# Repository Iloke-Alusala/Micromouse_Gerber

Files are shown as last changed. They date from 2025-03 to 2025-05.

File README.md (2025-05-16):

# 🐭 Micromouse Power Subsystem – UCT EEE3088F Design Project

This repository contains the KiCad schematic and PCB design files for the **power subsystem** of a modular micromouse robot, developed as part of the EEE3088F final year design course at the University of Cape Town.

---
# ⚠️ Warning: Do Not Use As-Is
This repository contains schematic and PCB design files for a micromouse power subsystem. These designs are provided for reference and educational purposes only.

Several components in the schematic and PCB do not function as intended due to design or implementation limitations, though many of the core design choices and ideas remain valid. Always check all datasheets of ICs and components used in a given section before adopting this to your own design.**

Therefore, this hardware should not be used as-is for production or critical applications.You are encouraged to use the files for inspiration or as a starting point, but please verify and test all circuits thoroughly before use in any real-world system.
---

## 📌 Project Overview

Micromouse robots are autonomous robots that solve mazes using onboard logic and control systems. This project focused on developing the **power subsystem**, a critical part of the micromouse architecture. The design was constrained by size (82mm x 60mm), budget (R600), and modularity requirements. The subsystem is responsible for:

- Supplying **regulated voltages** from the LiPo battery (3.3V and 5V)
- Enabling **bidirectional motor control**
- Charging a **single-cell LiPo battery** (200mA/600mA modes) from Type-C charging
- Providing **external load switching** for sensors and logic
- Supporting **testability** and **fault isolation**

---

## 🔧 Key Design Goals

- **Bidirectional Motor Driving** via dual DRV8833 H-Bridge ICs
- **Type C Battery Charging Support** using TP4056-MS and XL1509 buck converter, as well as the CH224K PD negotiator
- **High-Side Load Switching** through AP22966 ICs (1A per channel)
- **Modular Power Path** allowing buck and charger stages to be tested independently
- **Design-for-Testability** with test points, jumper-control pads, and 1206 resistor footprints
- **Battery Monitoring** using INA219 and I2C connection to external microcontroller
- **Regulated 5V and 3.3V ouptu voltages supporting 300mA and 1.5A outputs**
- **Physical ON-OFF switch for disabling and enabling battery connection to the board**

---

## 📁 Repository Structure
```bash
Micromouse_Power_Subsystem/
├── KiCad_Project/
├── power_subsystem.kicad_sch        # Schematic file
│  ├── power_subsystem.kicad_pcb        # PCB layout
│   ├── project.kicad_pro                # KiCad project file
│   └── gerber/                          # Output Gerber files
├── README.md
##

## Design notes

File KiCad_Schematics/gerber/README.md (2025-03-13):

# Micromouse_Gerber
A repository to store gerber files for our 3rd Year Micromouse Project. Make a mouse move through a maze

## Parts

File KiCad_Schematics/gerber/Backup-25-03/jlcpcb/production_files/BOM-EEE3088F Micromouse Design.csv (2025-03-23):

Comment | Designator | Footprint | LCSC | Quantity
0.1mF | C9 | C_0402_1005Metric_Pad0.74x0.62mm_HandSolder |  | 1
0.1mF | C7 | C_0402_1005Metric_Pad0.74x0.62mm_HandSolder |  | 1
0.1mF | C5 | C_0402_1005Metric_Pad0.74x0.62mm_HandSolder |  | 1
0.15 | R1 | R_1206_3216Metric_Pad1.30x1.75mm_HandSolder |  | 1
0.1mF | C12 | C_0402_1005Metric_Pad0.74x0.62mm_HandSolder |  | 1
DRV8837 | U2 | WSON-8-1EP_2x2mm_P0.5mm_EP0.9x1.6mm |  | 1
0.1mF | C4 | C_0402_1005Metric_Pad0.74x0.62mm_HandSolder |  | 1
0.1mF | C6 | C_0402_1005Metric_Pad0.74x0.62mm_HandSolder |  | 1
0.1mF | C3 | C_0402_1005Metric_Pad0.74x0.62mm_HandSolder |  | 1
DRV8837 | U3 | WSON-8-1EP_2x2mm_P0.5mm_EP0.9x1.6mm |  | 1
Conn_02x16_Odd_Even | J1 | PinSocket_2x16_P2.54mm_Vertical |  | 1
DRV8837 | U5 | WSON-8-1EP_2x2mm_P0.5mm_EP0.9x1.6mm |  | 1
0.1mF | C8 | C_0402_1005Metric_Pad0.74x0.62mm_HandSolder |  | 1
0.1mF | C2 | C_0402_1005Metric_Pad0.74x0.62mm_HandSolder |  | 1
INA219AxD | U1 | SOIC-8_3.9x4.9mm_P1.27mm |  | 1
0.1mF | C10 | C_0402_1005Metric_Pad0.74x0.62mm_HandSolder |  | 1
Conn_01x02 | J2 | JST_EH_B2B-EH-A_1x02_P2.50mm_Vertical |  | 1
0.1mF | C13 | C_0402_1005Metric_Pad0.74x0.62mm_HandSolder |  | 1
0.1mF | C11 | C_0402_1005Metric_Pad0.74x0.62mm_HandSolder |  | 1
DRV8837 | U4 | WSON-8-1EP_2x2mm_P0.5mm_EP0.9x1.6mm |  | 1

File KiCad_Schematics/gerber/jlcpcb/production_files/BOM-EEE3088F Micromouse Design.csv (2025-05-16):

Comment | Designator | Footprint | LCSC | Quantity
100uF | C56 | C_1206_3216Metric_Pad1.33x1.80mm_HandSolder | C15008 | 1
10uF | C41,C44,C45 | C_0805_2012Metric_Pad1.18x1.45mm_HandSolder | C15850 | 3
1nF | C35,C36 | C_0603_1608Metric | C1588 | 2
10k | R19 | R_0603_1608Metric_Pad0.98x0.95mm_HandSolder | C17414 | 1
330 | R28 | R_0805_2012Metric_Pad1.20x1.40mm_HandSolder | C17630 | 1
1 | R26,R35 | R_1206_3216Metric_Pad1.30x1.75mm_HandSolder | C17928 | 2
4.7k | R27 | R_1206_3216Metric_Pad1.30x1.75mm_HandSolder | C17936 | 1
AO3400A | Q2 | SOT-23 | C20917 | 1
22uH | L3,L4,L5 | L_7.3x7.3_H4.5 | C22463825 | 3
270 | R34 | R_0603_1608Metric_Pad0.98x0.95mm_HandSolder | C22966 | 1
2.2uF | C29,C31 | C_0603_1608Metric_Pad1.08x0.95mm_HandSolder | C23630 | 2
0.82 | R29,R30,R31,R32 | R_0603_1608Metric_Pad0.98x0.95mm_HandSolder | C3013351 | 4
SS32 | D3 | D_SMA | C34897 | 1
2.2k | R33 | R_0603_1608Metric_Pad0.98x0.95mm_HandSolder | C4190 | 1
AP22966DC8-7 | U13 | AP22966DC8-7 | C441830 | 1
DRV8833PW | U11,U12 | TSSOP-16_4.4x5mm_P0.65mm | C50506 | 2
1uF | C1,C27,C32,C33,C34 | C_0402_1005Metric_Pad0.74x0.62mm_HandSolder | C52923 | 5
10nF | C28,C30 | C_0603_1608Metric | C57112 | 2
XL1509-5.0 | U14 | SOIC-8_3.9x4.9mm_P1.27mm | C61063 | 1
100uF | C26,C48,C49,C50 | CP_EIA-3528-21_Kemet-B | C7196 | 4
TP4056-42-ESOP8 | U15 | SOIC-8-1EP_3.9x4.9mm_P1.27mm_EP2.41x3.3mm_ThermalVias | C7473158 | 1
47uF | C14,C15 | C_1206_3216Metric_Pad1.33x1.80mm_HandSolder | C96123 | 2
Conn_02x16_Odd_Even |  | PinSocket_2x16_P2.54mm_Vertical |  | 0
Conn_01x02 |  | JST_PH_B2B-PH-K_1x02_P2.00mm_Vertical |  | 0

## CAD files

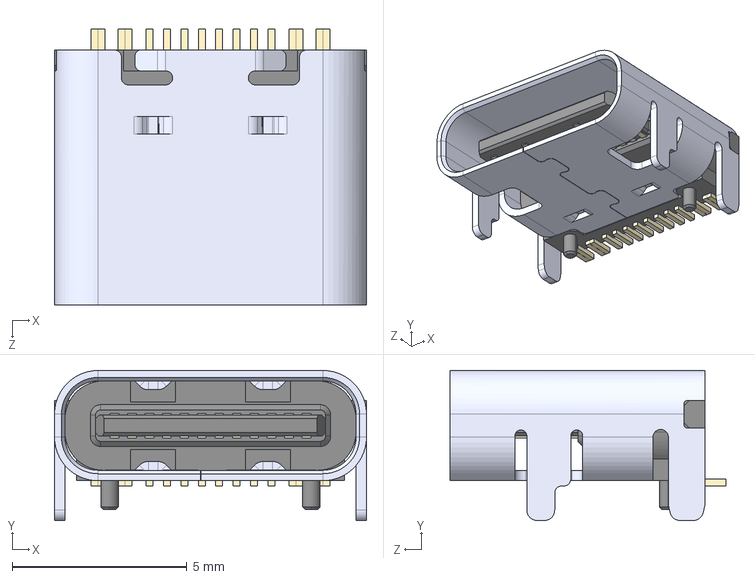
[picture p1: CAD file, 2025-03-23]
KiCad_Schematics/gerber/Backup-25-03/TYPE-C-31-M-12.step
8.94 x 4.30 x 7.90 mm

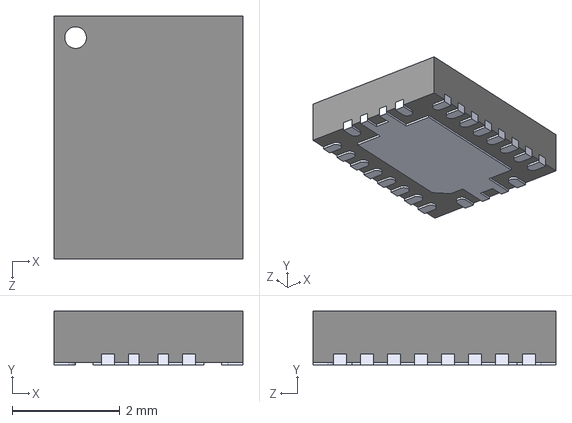
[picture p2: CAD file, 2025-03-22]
KiCad_Schematics/gerber/Backup-25-03/TPS61088/TPS61088RHLR.step
3.50 x 1.00 x 4.50 mm

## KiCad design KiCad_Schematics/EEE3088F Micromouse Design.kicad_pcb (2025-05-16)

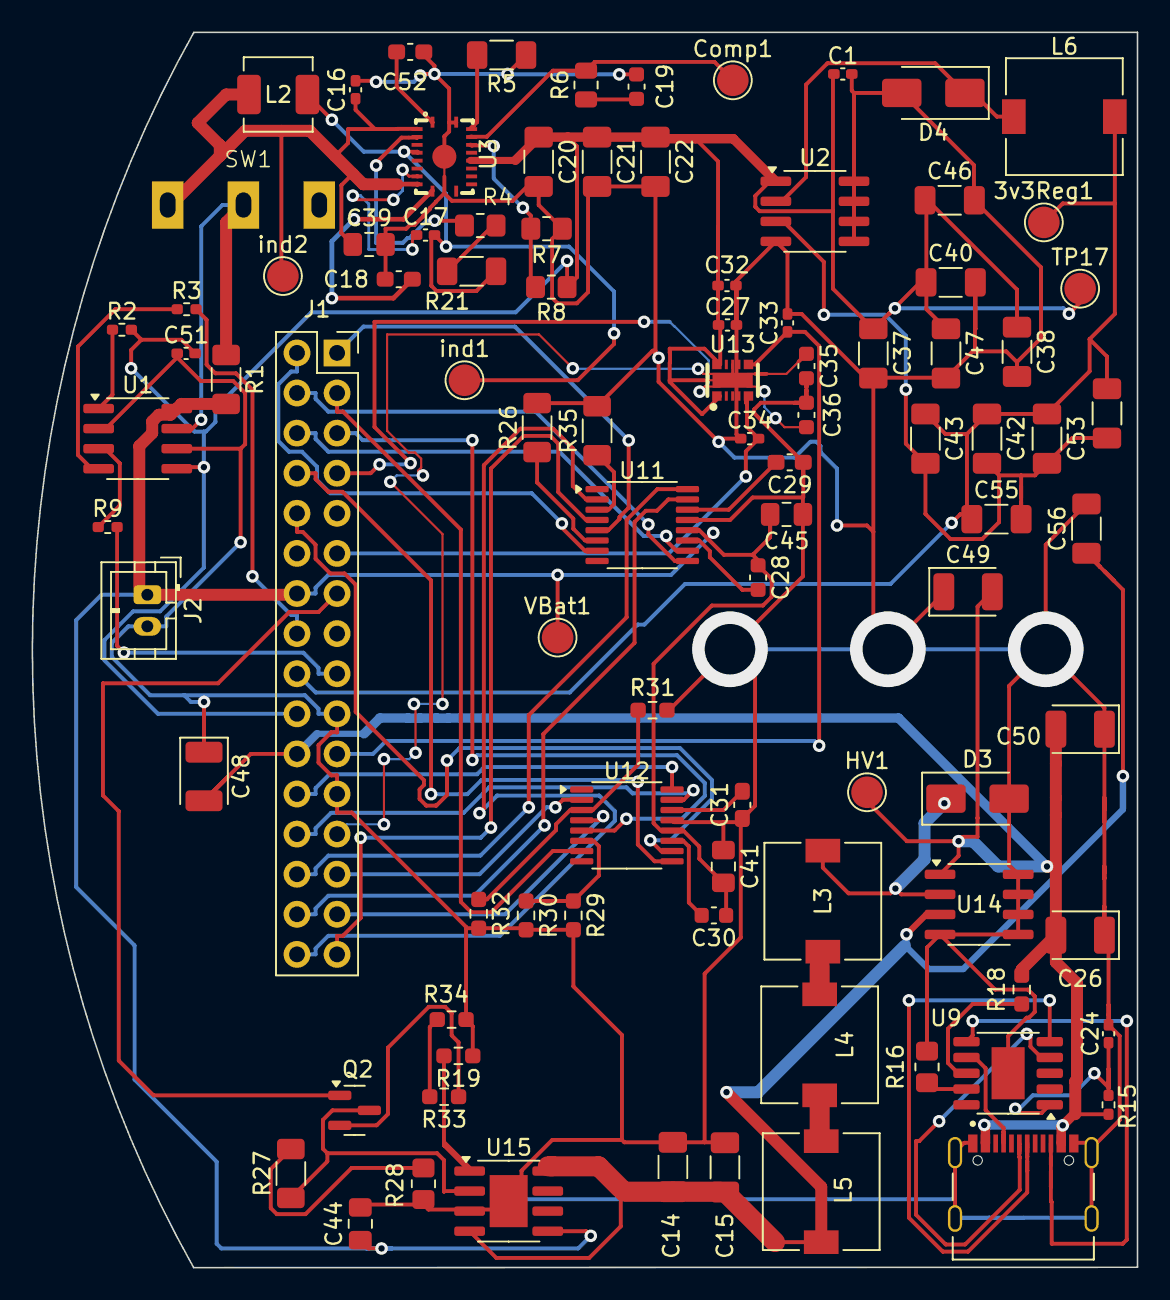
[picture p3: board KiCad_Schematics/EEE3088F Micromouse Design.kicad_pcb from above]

Board: 2 copper layers, 70.0 x 78.3 mm, 94 parts (0 on the bottom side), 71 nets.

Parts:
3v3Reg1: TestPoint; TestPoint_Pad_D2.0mm
C1, C24, C27, C32, C33, C34: 1uF; C_0402_1005Metric_Pad0.74x0.62mm_HandSolder
C14, C15, C42, C43, C47: 47uF; C_1206_3216Metric_Pad1.33x1.80mm_HandSolder
C16, C17, C51: 0.1uF; C_0402_1005Metric_Pad0.74x0.62mm_HandSolder
C18: 47nF; C_0603_1608Metric_Pad1.08x0.95mm_HandSolder
C19, C35, C36: 1nF; C_0603_1608Metric
C20, C21, C22: 22uF; C_1206_3216Metric_Pad1.33x1.80mm_HandSolder
C26, C48, C49, C50: 100uF; CP_EIA-3528-21_Kemet-B
C28, C30: 10nF; C_0603_1608Metric
C29, C31, C52: 2.2uF; C_0603_1608Metric_Pad1.08x0.95mm_HandSolder
C37, C38, C40, C46, C53, C54, C55, C56: 100uF; C_1206_3216Metric_Pad1.33x1.80mm_HandSolder
C39, C41, C44, C45: 10uF; C_0805_2012Metric_Pad1.18x1.45mm_HandSolder
Comp1: TestPoint; TestPoint_Pad_D2.0mm
D3, D4: SS32; D_SMA
HV1: TestPoint; TestPoint_Pad_D2.0mm
J1: Conn_02x16_Odd_Even; PinSocket_2x16_P2.54mm_Vertical
J2: Conn_01x02; JST_PH_B2B-PH-K_1x02_P2.00mm_Vertical
J3: TYPE-C-31-M-12; HRO_TYPE-C-31-M-12
L2: 1.2uH; L_Changjiang_FXL0420
L3, L4, L5, L6: 22uH; L_7.3x7.3_H4.5
Q2: AO3400A; SOT-23
R1: 0.1; R_1206_3216Metric_Pad1.30x1.75mm_HandSolder
R2, R3, R9: 3.3k; R_0402_1005Metric_Pad0.72x0.64mm_HandSolder
R4: 220k; R_0805_2012Metric_Pad1.20x1.40mm_HandSolder
R5: 100k; R_1206_3216Metric_Pad1.30x1.75mm_HandSolder
R6: 68k; R_0805_2012Metric
R7: 47k; R_0805_2012Metric_Pad1.20x1.40mm_HandSolder
R8: 150k; R_0805_2012Metric_Pad1.20x1.40mm_HandSolder
R15: 1k; R_0402_1005Metric_Pad0.72x0.64mm_HandSolder
R16: 6.8k; R_0805_2012Metric_Pad1.20x1.40mm_HandSolder
R18, R19: 10k; R_0603_1608Metric_Pad0.98x0.95mm_HandSolder
R21: 33k; R_1206_3216Metric_Pad1.30x1.75mm_HandSolder
R26, R35: 1; R_1206_3216Metric_Pad1.30x1.75mm_HandSolder
R27: 4.7k; R_1206_3216Metric_Pad1.30x1.75mm_HandSolder
R28: 330; R_0805_2012Metric_Pad1.20x1.40mm_HandSolder
R29, R30, R31, R32: 0.82; R_0603_1608Metric_Pad0.98x0.95mm_HandSolder
R33: 2.2k; R_0603_1608Metric_Pad0.98x0.95mm_HandSolder
R34: 270; R_0603_1608Metric_Pad0.98x0.95mm_HandSolder
SW1: SW_SPDT; SS12D10G4 071
TP17: TestPoint; TestPoint_Pad_D2.0mm
U1: INA219AxD; SOIC-8_3.9x4.9mm_P1.27mm
U2: XL1509-3.3; SOIC-8_3.9x4.9mm_P1.27mm
U3: TPS61088RHLR
U9: CH224K; SSOP-10-1EP_3.9x4.9mm_P1mm_EP2.1x3.3mm
U11, U12: DRV8833PW; TSSOP-16_4.4x5mm_P0.65mm
U13: AP22966DC8-7
U14: XL1509-5.0; SOIC-8_3.9x4.9mm_P1.27mm
U15: TP4056-42-ESOP8; SOIC-8-1EP_3.9x4.9mm_P1.27mm_EP2.41x3.3mm_ThermalVias
VBat1: TestPoint; TestPoint_Pad_D2.0mm
ind1, ind2: TestPoint; TestPoint_Pad_D2.0mm

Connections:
/3.3V Out: 3v3Reg1.1, C42.1, C43.1, C53.1, C54.1, C55.1, J1.18, L6.2
/5V Out: C1.1, C20.1, C21.1, C22.1, C27.1, C32.2, C37.1, C38.1, C40.1, C46.1, C47.1, C51.2, J1.20, R2.2, R8.2, TP17.1, U1.5 (VS), U2.1 (VIN), U3.15 (VOUT_14), U13.4 (VBIAS)
/CTRL_EXT_LOAD1: J1.25, U13.3 (EN1)
/CTRL_EXT_LOAD2: J1.7, U13.5 (EN2)
/EXT_LOAD1_OUT: C33.1, J1.21
/EXT_LOAD2_OUT: C34.2, J1.11
/FAST_CHARGE_CTRL: J1.13, Q2.1 (G)
/FB: R7.2, R8.1, U3.17 (FB)
/HV: C26.2, C48.2, C49.2, C50.2, HV1.1, J1.22, J3.A4_B9 (VBUS), J3.B4_A9 (VBUS), R15.1, R18.2, U14.1 (VIN)
/MOTOR1_A_OUT: J1.32, U11.2 (AOUT1)
/MOTOR1_B_OUT: J1.31, U11.4 (AOUT2)
/MOTOR1_CTRL1: J1.28, U11.16 (AIN1)
/MOTOR1_CTRL2: J1.30, U11.15 (AIN2)
/MOTOR2_CTRL1: J1.4, U11.9 (BIN1)
/MOTOR2_CTRL2: J1.6, U11.10 (BIN2)
/MOTOR3_A_OUT: J1.27, U12.2 (AOUT1)
/MOTOR3_B_OUT: J1.29, U12.4 (AOUT2)
/MOTOR3_CTRL1: J1.24, U12.16 (AIN1)
/MOTOR3_CTRL2: J1.26, U12.15 (AIN2)
/MOTOR4_CTRL1: J1.8, U12.9 (BIN1)
/MOTOR4_CTRL2: J1.10, U12.10 (BIN2)
/Motor2_A_OUT: J1.2, U11.7 (BOUT1)
/Motor2_B_OUT: J1.1, U11.5 (BOUT2)
/Motor4_A_OUT: J1.3, U12.7 (BOUT1)
/Motor4_B_OUT: J1.5, U12.5 (BOUT2)
/SCLK_INA219: J1.16, R3.2
/SDA_INA219: J1.17, R9.2
/Stepped Down 5V: C14.1, C15.1, C56.1, L5.2, U14.3 (FB), U15.4 (V_{CC}), U15.8 (CE)
/V_Battery+: C28.1, C30.1, C41.2, C44.1, C45.2, J1.14, J2.1, R1.2, U1.8 (IN+), U11.12 (VM), U12.12 (VM), U15.5 (BAT), VBat1.1
/Vcc: C16.2, C39.1, L2.1, SW1.1 (A), U3.2 (EN), U3.9 (VIN), ind2.1
GND: C1.2, C14.2, C15.2, C16.1, C18.2, C19.2, C20.2, C21.2, C22.2, C24.2, C26.1, C27.2, C29.1, C31.1, C32.1, C33.2, C34.1, C35.2, C36.2, C37.2, C38.2, C39.2, C40.2, C41.1, C44.2, C45.1, C46.2, C47.2, C48.1, C49.1, C50.1, C51.1, C52.1, C56.2, D3.2 (A), D4.2 (A), J1.19, J1.23, J2.2, J3.A1_B12 (GND), J3.B1_A12 (GND), J3.S1 (SHIELD), J3.S2 (SHIELD), J3.S3 (SHIELD), J3.S4 (SHIELD), R5.1, R7.1, R16.1, R19.1, R26.2, R28.2, R29.2, R30.2, R31.2, R32.2, R34.2, R35.2, U1.2 (A0), U1.6 (GND), U2.4 (~EN), U2.5 (GND), U2.6 (GND), U2.7 (GND), U2.8 (GND), U3.20 (AGND), U3.21 (PGND), U9.11 (GND), U11.13 (GND), U12.13 (GND), U13.11 (GND), U13.15 (EXP), U14.4 (~EN), U14.5 (GND), U14.6 (GND), U14.7 (GND), U14.8 (GND), U15.3 (GND), U15.9 (EPAD)
unnamed: C19.1, R6.1
unnamed: D3.1 (K), L3.1, U14.2 (OUT)
unnamed: D4.1 (K), L6.1, U2.2 (OUT)
unnamed: J3.A5 (CC1), U9.7 (CC1)
unnamed: J3.B5 (CC2), U9.6 (CC2)
unnamed: J3.A7 (DN1), U9.5 (DM)
unnamed: J3.A6 (DP1), U9.4 (DP)
unnamed: L3.2, L4.1
unnamed: L4.2, L5.1
unnamed: Q2.3 (D), R27.1, U15.2 (PROG)
unnamed: Q2.2 (S), R33.1
unnamed: R4.2, R21.2
unnamed: R27.2, R28.1
unnamed: R33.2, R34.1
unnamed: R1.1, SW1.2 (B), U1.7 (IN-)
unnamed: R2.1, U1.1 (A1)
unnamed: R3.1, U1.4 (SCL)
unnamed: R9.1, U1.3 (SDA)
unnamed: C42.2, C43.2, C53.2, C54.2, C55.2, U2.3 (FB)
unnamed: C17.1, U3.8 (BOOT)
unnamed: Comp1.1, R6.2, U3.18 (COMP)
unnamed: R4.1, U3.3 (FSW)
unnamed: R5.2, U3.19 (ILIM)
unnamed: C18.1, U3.10 (SS)
unnamed: C17.2, L2.2, R21.1, U3.5 (SW_4), ind1.1
unnamed: C52.2, U3.1 (VCC)
unnamed: R16.2, U9.9 (CFG1)
unnamed: R18.1, U9.8 (VBUS)
unnamed: C24.1, R15.2, U9.1 (VDD)
unnamed: R35.1, U11.3 (AISEN)
unnamed: R26.1, U11.6 (BISEN)
unnamed: C28.2, U11.11 (VCP)
unnamed: C29.2, U11.14 (VINT)
unnamed: R31.1, R32.1, U12.3 (AISEN)
unnamed: R29.1, R30.1, U12.6 (BISEN)
unnamed: C30.2, U12.11 (VCP)
unnamed: C31.2, U12.14 (VINT)
unnamed: C35.1, U13.12 (SS1)
unnamed: C36.1, U13.10 (SS2)
unnamed: R19.2, U15.1 (TEMP)

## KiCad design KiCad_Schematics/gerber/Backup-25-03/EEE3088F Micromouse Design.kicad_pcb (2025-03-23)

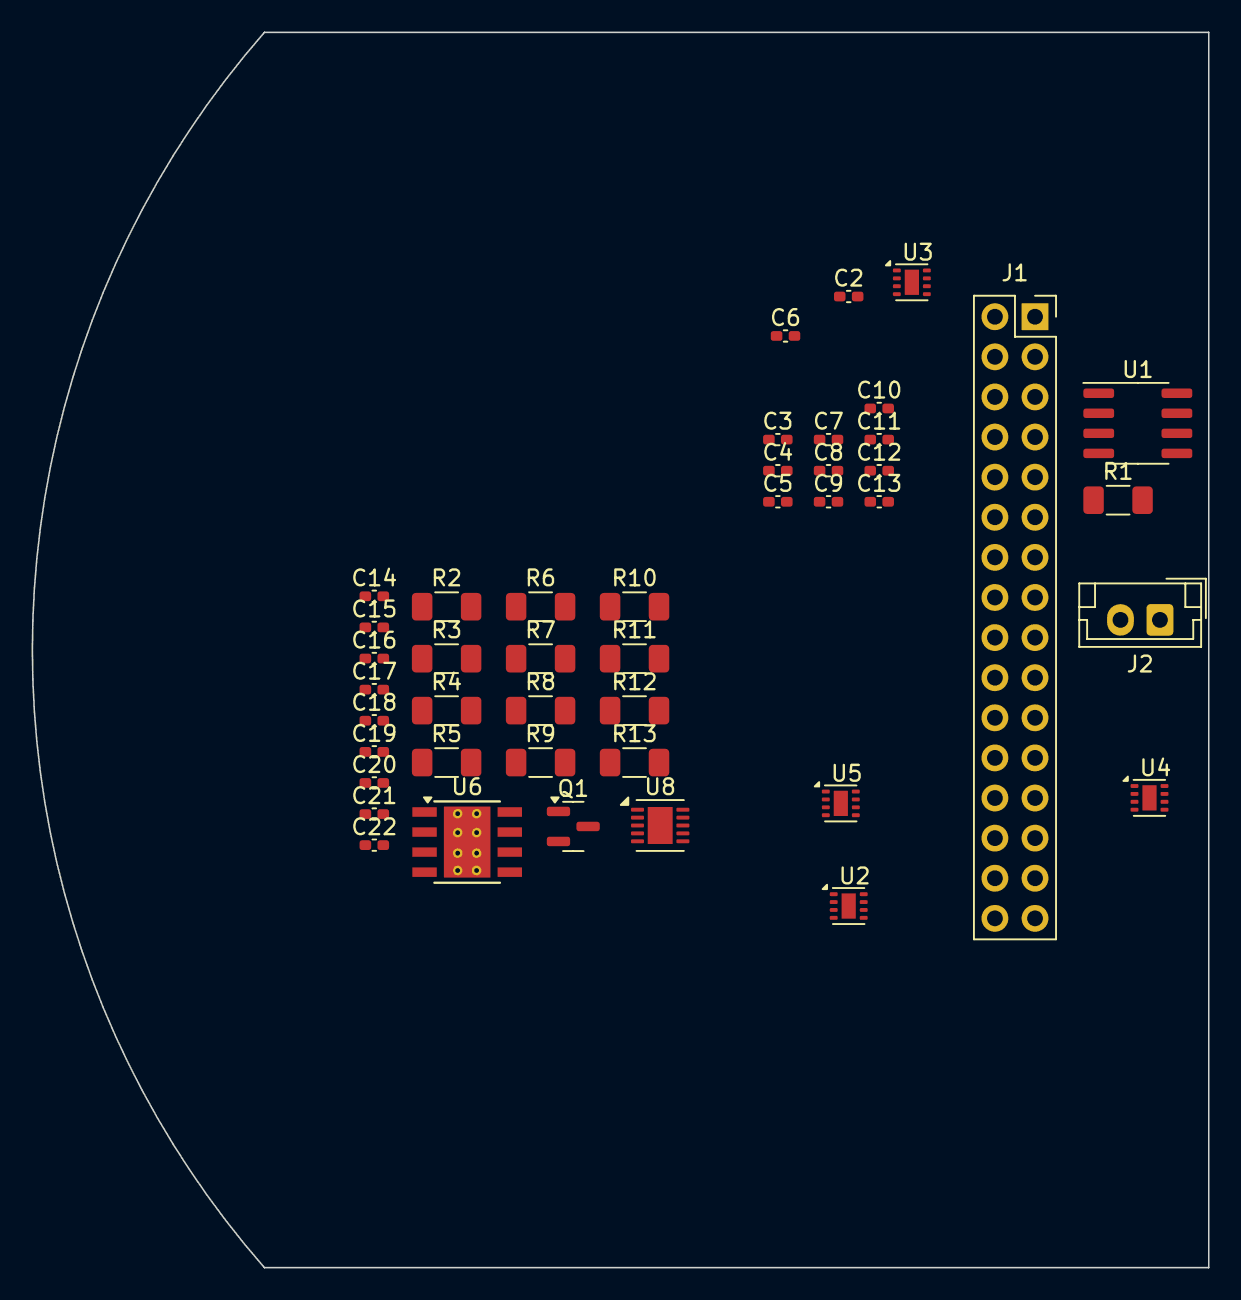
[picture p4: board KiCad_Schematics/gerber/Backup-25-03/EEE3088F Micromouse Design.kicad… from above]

Board: 2 copper layers, 74.5 x 78.2 mm, 44 parts (0 on the bottom side), 37 nets, no tracks yet.

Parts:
C2, C3, C4, C5, C6, C7, C8, C9, C10, C11, C12, C13, C14: 0.1mF; C_0402_1005Metric_Pad0.74x0.62mm_HandSolder
C15: 10uF; C_0402_1005Metric_Pad0.74x0.62mm_HandSolder
C16, C17: 0.1uF; C_0402_1005Metric_Pad0.74x0.62mm_HandSolder
C18: 47nF; C_0402_1005Metric_Pad0.74x0.62mm_HandSolder
C19: 22pF; C_0402_1005Metric_Pad0.74x0.62mm_HandSolder
C20, C21, C22: 22uF; C_0402_1005Metric_Pad0.74x0.62mm_HandSolder
J1: Conn_02x16_Odd_Even; PinSocket_2x16_P2.54mm_Vertical
J2: Conn_01x02; JST_EH_B2B-EH-A_1x02_P2.50mm_Vertical
Q1: AO3400A; SOT-23
R1: 0.15; R_1206_3216Metric_Pad1.30x1.75mm_HandSolder
R2: 5.6k; R_1206_3216Metric_Pad1.30x1.75mm_HandSolder
R3: 3.3k; R_1206_3216Metric_Pad1.30x1.75mm_HandSolder
R4: 255k; R_1206_3216Metric_Pad1.30x1.75mm_HandSolder
R5: 100k; R_1206_3216Metric_Pad1.30x1.75mm_HandSolder
R6, R13: 10k; R_1206_3216Metric_Pad1.30x1.75mm_HandSolder
R7: 47k; R_1206_3216Metric_Pad1.30x1.75mm_HandSolder
R8: 150k; R_1206_3216Metric_Pad1.30x1.75mm_HandSolder
R9: 4.7k; R_1206_3216Metric_Pad1.30x1.75mm_HandSolder
R10: 330; R_1206_3216Metric_Pad1.30x1.75mm_HandSolder
R11: 2.2k; R_1206_3216Metric_Pad1.30x1.75mm_HandSolder
R12: 270; R_1206_3216Metric_Pad1.30x1.75mm_HandSolder
U1: INA219AxD; SOIC-8_3.9x4.9mm_P1.27mm
U2, U3, U4, U5: DRV8837; WSON-8-1EP_2x2mm_P0.5mm_EP0.9x1.6mm
U6: TPS5430DDA; TI_SO-PowerPAD-8_ThermalVias
U8: MCP73833-xxx-MF; DFN-10-1EP_3x3mm_P0.5mm_EP1.58x2.35mm

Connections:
/3.3V Out: J1.18, R2.2
/3.3V Regulated: C4.2, C7.2, C10.2, C13.2, U2.1 (VM), U3.1 (VM), U4.1 (VM), U5.1 (VM)
/5V Out: C3.1, C5.1, C8.1, C11.1, C20.1, C21.1, C22.1, J1.20, R8.2, U2.7 (~SLEEP), U3.7 (~SLEEP), U4.7 (~SLEEP), U5.7 (~SLEEP), U8.1 (V_{DD}), U8.2 (V_{DD})
/FAST_CHARGE_CTRL: J1.13, Q1.1 (G)
/MOTOR1_A_OUT: J1.32, U2.2 (OUT1)
/MOTOR1_B_OUT: J1.31, U2.3 (OUT2)
/MOTOR1_CTRL1: J1.28, U2.6 (IN1)
/MOTOR1_CTRL2: J1.30, U2.5 (IN2)
/MOTOR2_CTRL1: J1.4, U3.6 (IN1)
/MOTOR2_CTRL2: J1.6, U3.5 (IN2)
/MOTOR3_A_OUT: J1.27, U4.2 (OUT1)
/MOTOR3_B_OUT: J1.29, U4.3 (OUT2)
/MOTOR3_CTRL1: J1.24, U4.6 (IN1)
/MOTOR3_CTRL2: J1.26, U4.5 (IN2)
/MOTOR4_CTRL1: J1.8, U5.6 (IN1)
/MOTOR4_CTRL2: J1.10, U5.5 (IN2)
/Motor2_A_OUT: J1.2, U3.2 (OUT1)
/Motor2_B_OUT: J1.1, U3.3 (OUT2)
/Motor4_A_OUT: J1.3, U5.2 (OUT1)
/Motor4_B_OUT: J1.5, U5.3 (OUT2)
/Motor_H_Supply: C2.1, C6.1, C9.1, C12.1
/SCLK_INA219: J1.16, U1.4 (SCL)
/SDA_INA219: J1.17, U1.3 (SDA)
/V_Battery+: J2.1, R1.2, U1.1 (A1), U1.5 (VS), U1.8 (IN+), U8.9 (V_{BAT}), U8.10 (V_{BAT})
/V_Battery-: J2.2, U1.2 (A0)
/Vcc: C15.1, C16.2, R1.1, U1.7 (IN-), U6.7 (VIN)
GND: C2.2, C3.2, C4.1, C5.2, C6.2, C7.1, C8.2, C9.2, C10.1, C11.2, C12.2, C13.1, C15.2, C16.1, C18.2, C19.2, C20.2, C21.2, C22.2, R3.1, R5.1, R7.1, R7.2, R8.1, R10.2, R12.2, R13.2, U1.6 (GND), U2.4 (GND), U2.8 (VCC), U2.9 (GND), U3.4 (GND), U3.8 (VCC), U3.9 (GND), U4.4 (GND), U4.8 (VCC), U4.9 (GND), U5.4 (GND), U5.8 (VCC), U5.9 (GND), U6.6 (GND), U6.9 (GNDPAD), U8.5 (V_{SS}), U8.11 (EP)
unnamed: C19.1, R6.1
unnamed: C14.1, U6.8 (PH)
unnamed: Q1.3 (D), R9.1, U8.6 (PROG)
unnamed: Q1.2 (S), R11.1
unnamed: R9.2, R10.1
unnamed: R11.2, R12.1
unnamed: C14.2, U6.1 (BOOT)
unnamed: R2.1, R3.2, U6.4 (VSENSE)
unnamed: C17.2, R4.2
unnamed: R13.1, U8.8 (THERM)

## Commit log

2025-03-22 Added KiCad Document files
    [EEE3088F Micromouse Design.kicad_pcb, EEE3088F Micromouse Design.kicad_sch]
2025-03-22 Added DRV8837 Motor Driver x4. Footprint PCB Organisation outstanding
    [EEE3088F Micromouse Design.kicad_pcb, EEE3088F Micromouse Design.kicad_sch]
2025-03-22 Added 3.3V and 5V outputs
    [CPL-EEE3088F Micromouse Design.csv, EEE3088F Micromouse Design-CuBottom.gbr, EEE3088F Micromouse Design-CuTop.gbr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]
2025-03-23 Minor change to voltage regulator
    [EEE3088F Micromouse Design.kicad_sch]
2025-03-23 Added a switch to the battery
    [EEE3088F Micromouse Design.kicad_sch]
2025-03-23 Added USB Type-C Connector
    [EEE3088F Micromouse Design.kicad_sch, TYPE-C-31-M-12.step]
2025-03-23 Added the Battery Charging Circuit
    [BOM-EEE3088F Micromouse Design.csv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]
2025-03-24 Added Type-C 9V integration
    [EEE3088F Micromouse Design.kicad_sch]
2025-03-24 Fixed some connector labels
    [EEE3088F Micromouse Design.kicad_sch]
2025-03-24 Redid the Motor circuit with an Improved IC
    [EEE3088F Micromouse Design.kicad_sch]
2025-03-24 Added and fixed the external load switching to an IC instead of discrete components.
    [EEE3088F Micromouse Design.kicad_sch]
2025-03-25 Added 9V -> 5V Buck Converter to feed regulated 5V to Charging IC
    [EEE3088F Micromouse Design.kicad_sch]
2025-03-25 Added parallel resistor combination for 500mA motor. Easier E12 configuration and cheaper
    [EEE3088F Micromouse Design.kicad_sch]
2025-03-25 Added switch changed some stuff to be E12
    [EEE3088F Micromouse Design.kicad_sch]
2025-03-25 Changed Battery Charger to single IC and reformatted components
    [EEE3088F Micromouse Design.kicad_sch]
2025-03-25 Removed the graveyard and restructured board
    [BOM-EEE3088F Micromouse Design.csv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]
2025-03-25 Added items to BOM. Need to finish assignment
    [EEE3088F Micromouse Design.kicad_pcb, EEE3088F Micromouse Design.kicad_sch]
2025-03-25 Adding JLC part numbers
    [EEE3088F Micromouse Design.kicad_pcb, EEE3088F Micromouse Design.kicad_sch]
2025-03-25 Added footprints to 2 of 3 subcircuits
    [EEE3088F Micromouse Design.kicad_sch]
2025-03-25 Added footprints, external load switching is the last circuit that needs labeling and then circuit verification and double checking
    [EEE3088F Micromouse Design.kicad_sch]
2025-03-26 Added footprints for ICs and imported components
    [EEE3088F Micromouse Design.kicad_pcb, EEE3088F Micromouse Design.kicad_sch]
2025-03-26 Corrected some footprints and matched LCSC numbers to parts on pcb layout page
    [BOM-EEE3088F Micromouse Design.csv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]
2025-03-26 Added more footprints
    [EEE3088F Micromouse Design.kicad_pcb, EEE3088F Micromouse Design.kicad_sch]
2025-03-26 Switch time
2025-03-26 Please Read: Replaced buck converter, removed old ones but this has left behind a gap in the copper. The board also needs a curved arc according to Justin. Still need footprints for key ICs, connecto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
    [EEE3088F Micromouse Design.kicad_pcb, EEE3088F Micromouse Design.kicad_sch, freerouting.dsn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]
2025-03-27 Added footprints for inductors and tantalum capacitors. Also merged buck back to charging IC, and added test points
    [EEE3088F Micromouse Design.kicad_pcb, EEE3088F Micromouse Design.kicad_sch, TYPE-C-31-M-12.step]
2025-03-27 Added footprints for inductor, switch and type-c connector
    [EEE3088F Micromouse Design.kicad_pcb, EEE3088F Micromouse Design.kicad_sch]
2025-03-27 Fixed the arc to match spec. Added Daniel's components and added all LCSC numbers for them. Fixed the connector footprint, although JST one still needs to be corrected
    [EEE3088F Micromouse Design.kicad_pcb, EEE3088F Micromouse Design.kicad_sch]
2025-03-27 Added some text on the silkscreen to delimit the modules
    [EEE3088F Micromouse Design.kicad_pcb]
2025-03-27 Found the correct Battery connector
    [EEE3088F Micromouse Design.kicad_pcb, EEE3088F Micromouse Design.kicad_sch]
2025-03-27 Added test points and an inductor that was not populated. Added labels
    [EEE3088F Micromouse Design.kicad_pcb, EEE3088F Micromouse Design.kicad_sch]
2025-03-27 Found a component that I had not footprinted yet. use the footprint list to check yours please
    [EEE3088F Micromouse Design.kicad_pcb, EEE3088F Micromouse Design.kicad_sch]
2025-03-27 Added a bunch of changes
    [BOM-EEE3088F Micromouse Design.csv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]
2025-03-27 Updated the INA219 circuit
    [EEE3088F Micromouse Design.kicad_pcb, EEE3088F Micromouse Design.kicad_sch, freerouting.dsn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]
2025-03-27 First turnover, changed pcb layout
    [BOM-EEE3088F Micromouse Design.csv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]
2025-03-27 Fixing errors
    [EEE3088F Micromouse Design.kicad_pcb, freerouting.dsn, temp-freerouting.dsn]
2025-03-28 Started routing PCB
    [EEE3088F Micromouse Design.kicad_pcb, EEE3088F Micromouse Design.kicad_sch]
2025-03-28 Finishing off
    [EEE3088F Micromouse Design.kicad_pcb, EEE3088F Micromouse Design.kicad_sch]
2025-03-28 Finishing off. V2
    [BOM-EEE3088F Micromouse Design.csv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]
2025-03-28 Too tired
    [EEE3088F Micromouse Design.kicad_pcb]
2025-05-10 Latest force push
    [BOM-EEE3088F Micromouse Design.csv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]
2025-05-16 Performing Final Organisation Nuke
    [BOM-EEE3088F Micromouse Design.csv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]
